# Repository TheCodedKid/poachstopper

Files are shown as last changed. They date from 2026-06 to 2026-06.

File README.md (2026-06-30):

<div align="center">

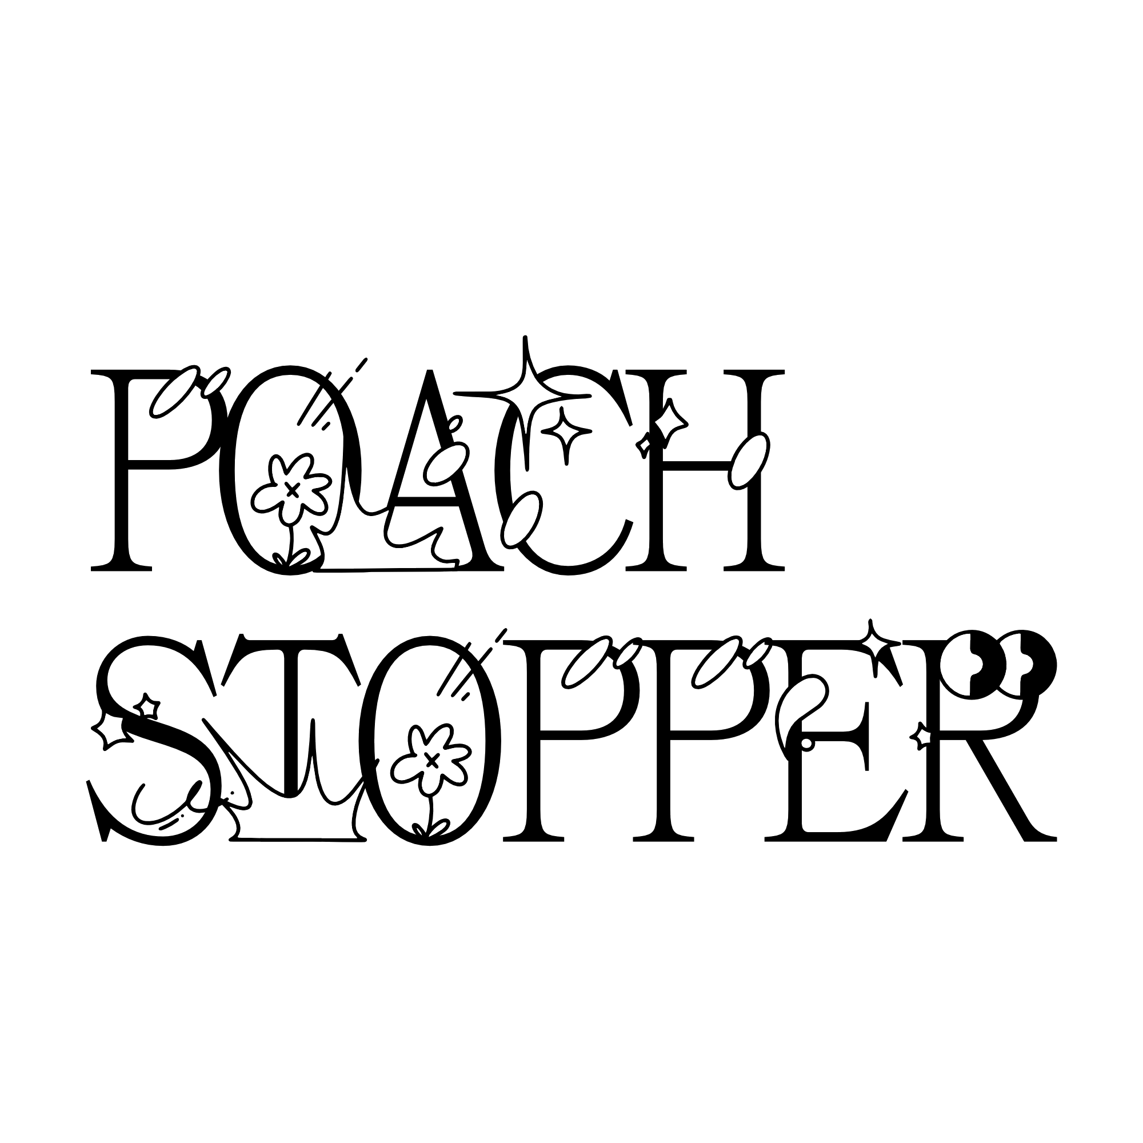
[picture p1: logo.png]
Poach Stopper


**Inline soft-start for Mini Cheetah motor controllers.**
Stops the power-on inrush surge that kills the input caps.

</div>

---

## Why

Cheap MIT Mini Cheetah clones have undersized input caps and no inrush limiting. Hot-plugging a charged battery, current spike into the FETs, caps die. No good, dead cheetah.

Poach Stopper splices inline on the battery lead, pre-charges through a resistor, then hands over full current. No MCU, no firmware, no buttons.

Delay time is calculated to be about `0.24` seconds, but this is due to nearly zero documentation on the knockoff motor's cap bank size, so this is more of a safety number + I think you can wait a quarter second, but if this is not the case, submit an issue.

## How it works

| Block | Parts | Job |
|---|---|-----|
| Soft-start bypass | G2RL-1A relay + R3 (10 Ω 5 W) | limits inrush; relay shorts it once charged |
| Delay timer | NE555 monostable mode |
| 5 V rail | LMR16006 buck, 24 V → 5 V | Powers the 555 + relay coil off the pack |
| Protection | Blade fuse F1, 1N4007 flyback D3 | Fault current + coil kickback |

<div align="center">

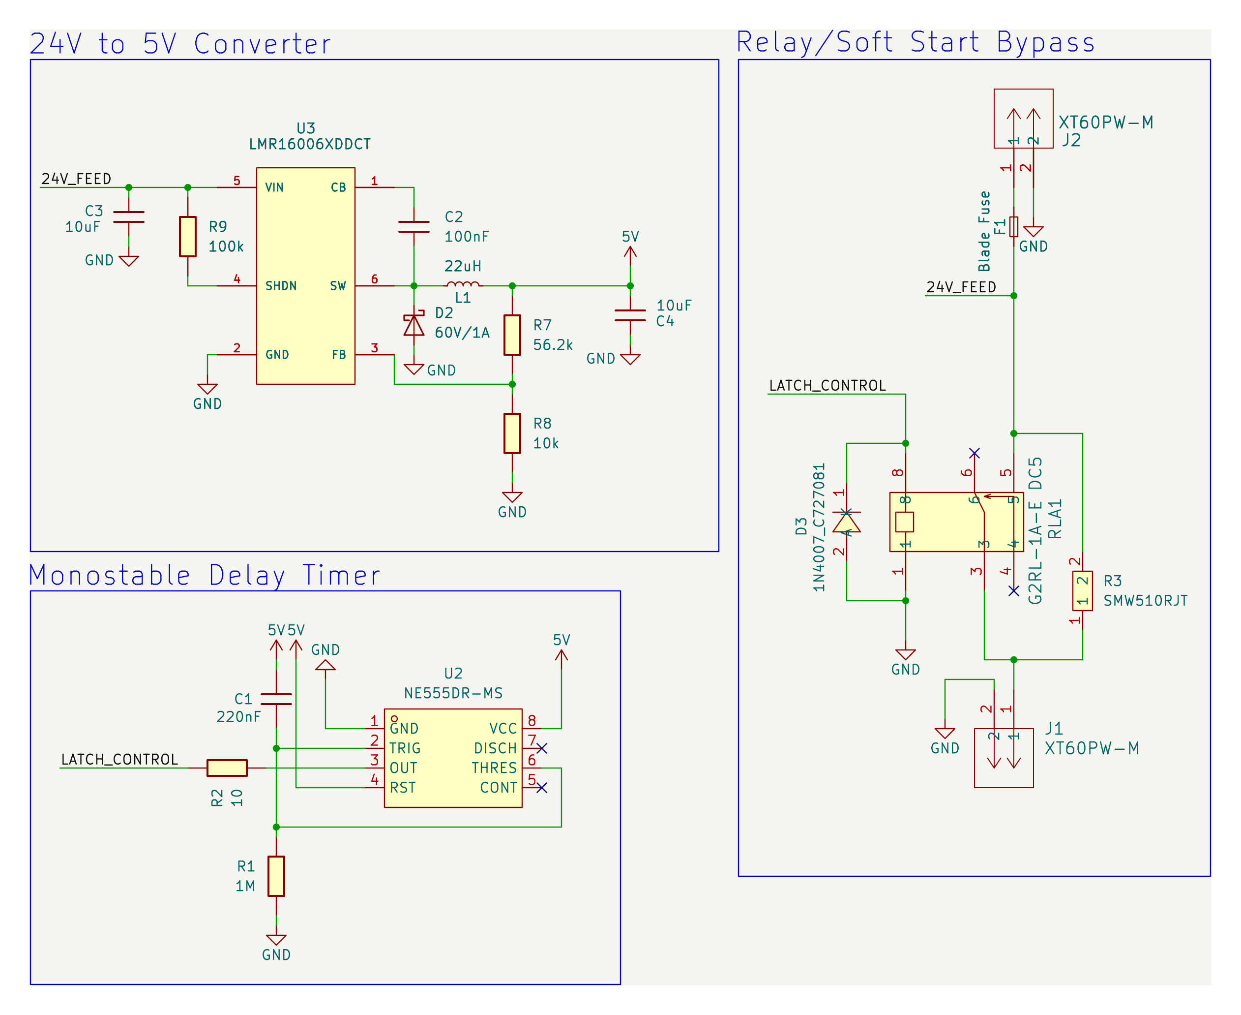
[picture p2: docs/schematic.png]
Schematic

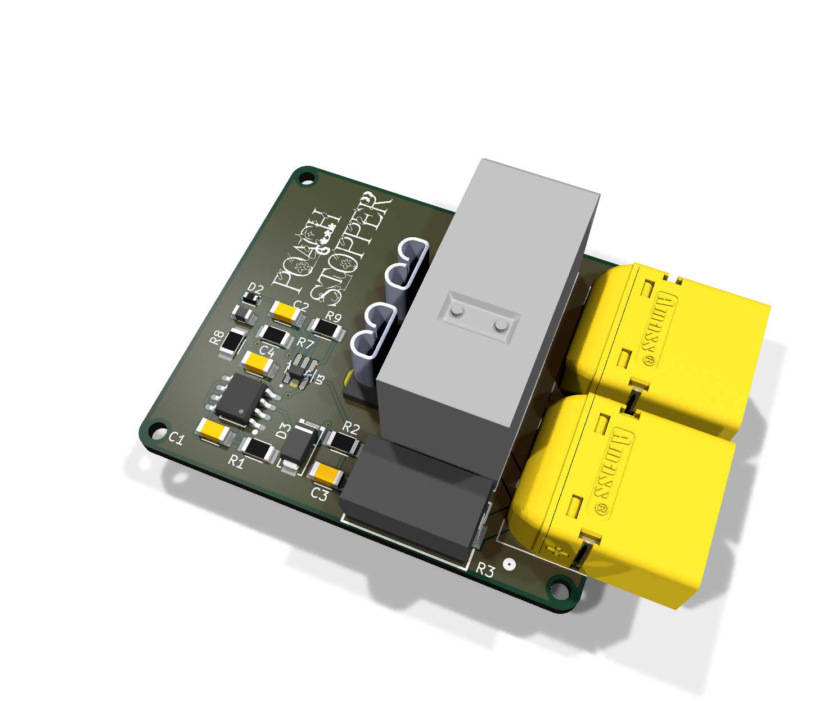
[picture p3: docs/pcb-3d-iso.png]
PCB 3D

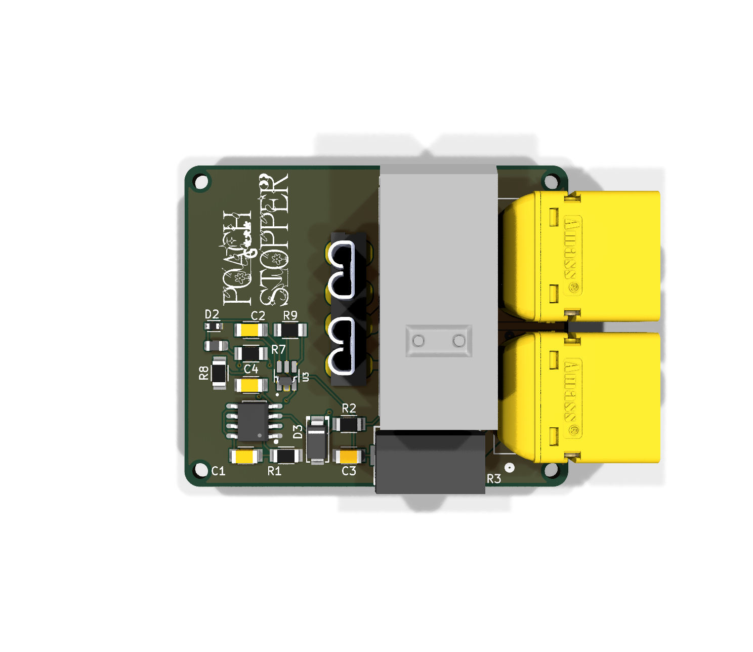
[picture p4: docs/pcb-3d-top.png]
PCB top


</div>

## Build it

JLCPCB order files are in `fab/`:

- `fab/poachstopper-gerbers.zip` — gerbers
- `fab/poachstopper-cpl.csv` — pick-and-place
- `bom/jlcpcb_bom.csv` — assembly BOM (LCSC parts)

**Hand-solder yourself** (not on PnP BOM): R3 (10 Ω 5 W), F1 fuse holder, RLA1 relay, XT60 connectors J1/J2.

Source is KiCad 10 — open `poachstopper.kicad_pro`.

## License

[MIT](LICENSE) © 2026 TheCodedKid

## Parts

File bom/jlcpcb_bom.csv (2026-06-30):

Comment | Designator | Footprint | LCSC Part #
220nF | C1 | 1206 | C107186
100nF | C2 | 1206 | C24497
10uF | C3 | 1206 | C13585
10uF | C4 | 1206 | C13585
60V/1A | D2 | Diode_Schottky_0603 | C3759853
1N4007 | D3 | SMA_L4.3-W2.5-LS5.0-RD | C727081
22uH | L1 | 0805 | C6364733
1M | R1 | 1206 | C17927
10 | R2 | 1206 | C17903
56.2k | R7 | 1206 | C2999490
10k | R8 | 1206 | C17902
100k | R9 | 1206 | C17900
NE555DR-MS | U2 | SOIC-8_L4.9-W3.9-P1.27-LS6.0-BL | C7434189
LMR16006XDDCT | U3 | SOT95P280X110-6N | C87080

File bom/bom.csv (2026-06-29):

Reference | Qty | Value | Footprint | MPN | Manufacturer | LCSC | LC_Stock | Chosen_Distributor | Datasheet | Validated | DNP | Notes
C1 | 1 | 220nF | 1206 |  |  | C107186 |  |  | https://www.yageo.com/upload/media/product/productsearch/datasheet/mlcc/UPY-GP_NP0_16V-to-50V_18.pdf
D2 | 1 | 60V/1A | Diode_Schottky_0603 |  |  | C3759853 |  |  | https://www.digikey.com/en/products/detail/bourns-inc/CD0603-B0340R/7796828
D3 | 1 | 1N4007 | SMA_L4.3-W2.5-LS5.0-RD | 1N4007 | TWGMC(迪嘉) | C727081 |  |  | https://lcsc.com/product-detail/Diodes-General-Purpose_TWGMC-1N4007_C727081.html |  |  | SMD swap (SMA/DO-214AC) - change footprint from DO-41 before fab
F1 | 1 | Blade Fuse | Fuseholder_Automotive |  |  |  |  |  | https://www.keyelco.com/userAssets/file/M65p41.pdf |  | yes | Hand-solder, exclude from JLCPCB pick-and-place (DNP)
J1,J2 | 2 | XT60PW-M | CONN_XT60PW-M_AMA |  |  |  |  |  | XT60PW-M |  | yes | XT60 - order + solder separately, exclude from JLCPCB PnP (DNP)
L1 | 1 | 22uH | 0805 |  |  | C6364733 |  |  | https://mm.digikey.com/Volume0/opasdata/d220001/medias/docus/1221/MBKK2012T1R0M_SS.pdf
R1 | 1 | 1M | 1206 |  |  | C17927
R2 | 1 | 10 | 1206 |  |  | C17903
R3 | 1 | 10 | RES-SMD_L13.5-W7.3 | SMW510RJT | TE Connectivity(泰科电子) | C2094091 |  |  | https://www.lcsc.com/datasheet/C2094091.pdf |  |  | 10R 5W SMD - change footprint from 3550 to RES-SMD_L13.5-W7.3 before fab
R7 | 1 | 56.2k | 1206 |  |  | C2999490
R8 | 1 | 10k | 1206 |  |  | C17902
R9 | 1 | 100k | 1206 |  |  | C17900
RLA1 | 1 | G2RL-1A-E DC5 | RELAY_G2RL-1A-E_DC5_OMR |  |  |  |  |  | G2RL-1A-E DC5 |  | yes | Relay - order + solder separately, exclude from JLCPCB PnP (DNP)
U2 | 1 | NE555DR-MS | SOIC-8_L4.9-W3.9-P1.27-LS6.0-BL | NE555DR-MS | MSKSEMI(美森科) | C7434189 |  |  | https://www.lcsc.com/datasheet/C7434189.pdf
U3 | 1 | LMR16006XDDCT | SOT95P280X110-6N |  |  | C87080

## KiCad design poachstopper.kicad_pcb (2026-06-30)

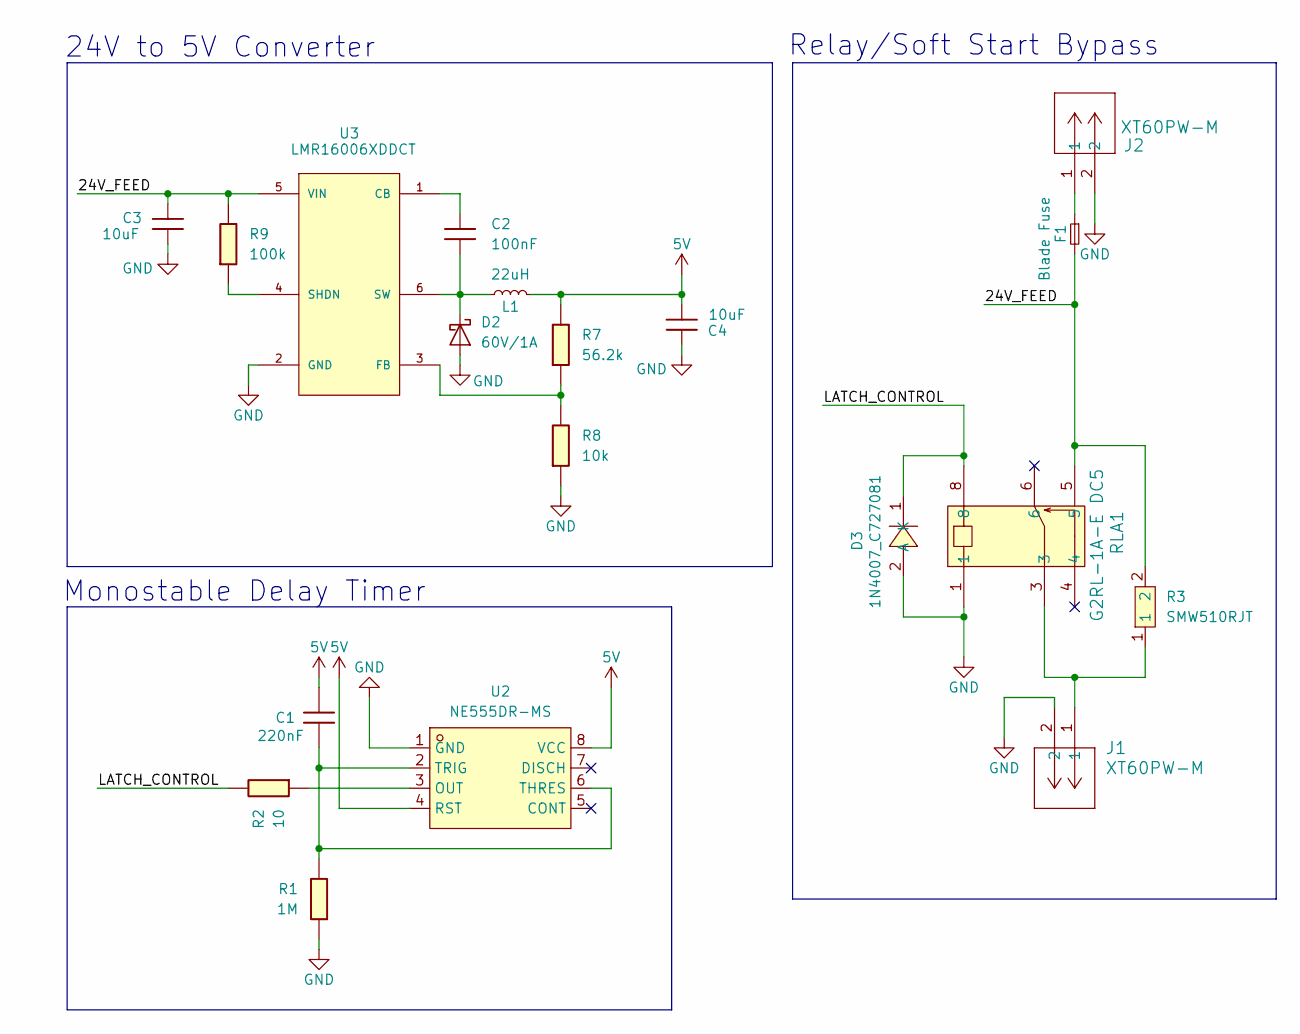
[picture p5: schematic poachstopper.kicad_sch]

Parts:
C1: 220nF; C_1206
C2: 100nF; C_1206
C3, C4: 10uF; C_1206
D2: 60V/1A; Diode_Schottky_0603
D3: 1N4007_C727081; SMA_L4.3-W2.5-LS5.0-RD; MPN 1N4007; LCSC Part C727081
F1: Blade Fuse; Fuseholder_Automotive
J1, J2: XT60PW-M; CONN_XT60PW-M_AMA
L1: 22uH; 0805
R1: 1M; R_1206
R2: 10; R_1206
R3: SMW510RJT; RES-SMD_L13.5-W7.3; MPN SMW510RJT; LCSC Part C2094091
R7: 56.2k; R_1206
R8: 10k; R_1206
R9: 100k; R_1206
RLA1: G2RL-1A-E DC5; RELAY_G2RL-1A-E_DC5_OMR
U2: NE555DR-MS; SOIC-8_L4.9-W3.9-P1.27-LS6.0-BL; MPN NE555DR-MS; LCSC Part C7434189
U3: LMR16006XDDCT; SOT95P280X110-6N

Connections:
5V: C1.1, C4.2, L1.2, R7.1, U2.4 (RST), U2.8 (VCC)
/24V_FEED: C3.1, F1.2, R3.2, R9.1, RLA1.5, U3.5 (VIN)
/LATCH_CONTROL: D3.1 (K), R2.1, RLA1.8
GND: C3.2, C4.1, D2.2 (A), D3.2 (A), J1.2, J2.2, R1.2, R8.2, RLA1.1, U2.1 (GND), U3.2 (GND)
unnamed: C2.2, D2.1 (K), L1.1, U3.6 (SW)
unnamed: F1.1, J2.1
unnamed: J1.1, R3.1, RLA1.3
unnamed: R2.2, U2.3 (OUT)
unnamed: C1.2, R1.1, U2.2 (TRIG), U2.6 (THRES)
unnamed: C2.1, U3.1 (CB)
unnamed: R7.2, R8.1, U3.3 (FB)
unnamed: R9.2, U3.4 (SHDN)

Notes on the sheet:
24V to 5V Converter
Relay/Soft Start Bypass
Monostable Delay Timer

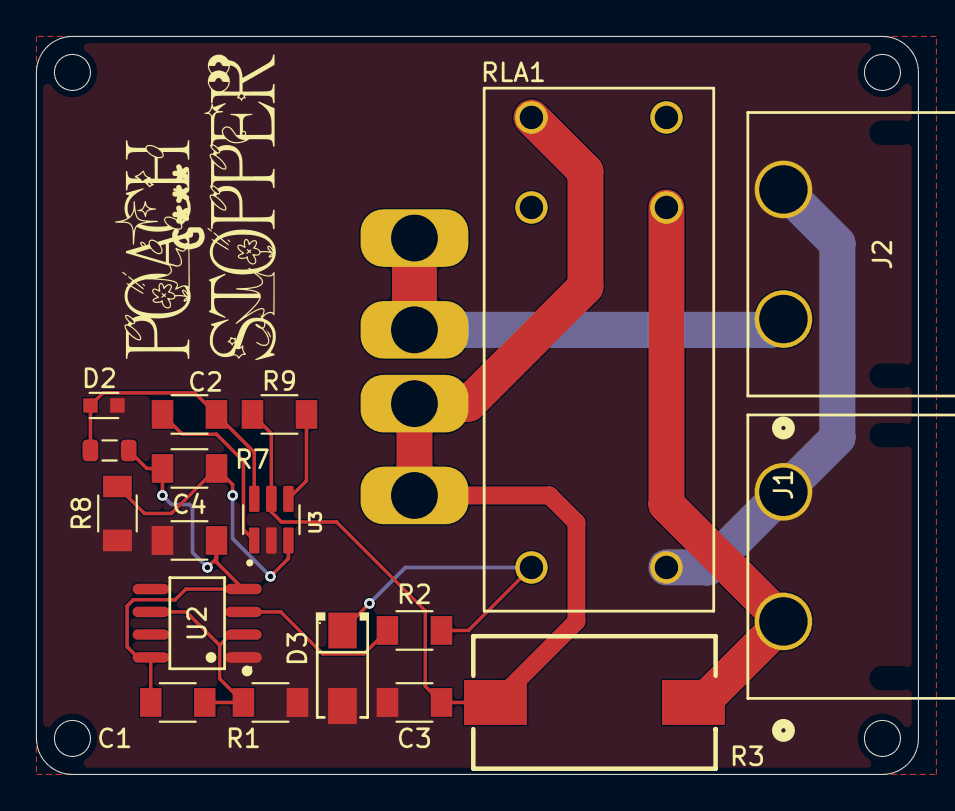
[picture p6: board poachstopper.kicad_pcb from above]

Board: 2 copper layers, 49.0 x 41.0 mm, 19 parts (0 on the bottom side), 12 nets.

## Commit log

2026-06-22 draft created
    [poachstopper.kicad_pcb, poachstopper.kicad_sch]
2026-06-22 going running
    [poachstopper.kicad_sch]
2026-06-29 circuit cleanup, functionality finalized, BOM
    [bom.csv, jlcpcb_bom.csv, poachstopper.kicad_pcb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]
2026-06-30 removed slop documentation
    [poachstopper.kicad_pcb]
